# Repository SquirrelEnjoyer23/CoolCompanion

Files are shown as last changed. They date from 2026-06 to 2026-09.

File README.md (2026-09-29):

# Cool Companion



## Cool yourself down today!

A smart table top fan, with adjustable speed and temperature sensing, all powered by usb c.

Perfect for any summer day, or any day... if you just want to move air around.

# Features

This "Cool" fan helps you always stay cool by having adjustable speed and the ability to turn on and off depending on the rooms temperature allowing you to stay cool without the extra work of turning a fan on and off, and on top of that the fan is from Noctua allowing it to be extremely silent as to not interfere with you.

# How to properly use it

The machine is used by plugging a USB C cable into the back, the device requires 5v at 1 Amp, and once its plugged it in does its startup and then you are good to go, turning the knob changes the speed and pressing the knob changes the modes allowing you to use the temperature mode and to turn that back off just turn the temperature requirement back down to zero. with device information available on the screen as well such as current room temp, target temprature and fan speed

# AI Disclosure
This project contains some AI generated code, AI was used for bug finding and putting in features I couldn't find documentation on, as well as adding some polish to the code to have it function a bit smoother for the user.

# What happened?
This project took a absolutely WILD amount of time over the summer due to technical difficulties it only officially recorded about ~43 hours but it took me way more than that in debugging, as well as the sheer number of boards I had to try before finally getting a working one.





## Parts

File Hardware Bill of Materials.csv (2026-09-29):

Item Name | Qty | Price (total) (USD) | Item link | Notes
Noctua Fan | 1 | $34.95 | https://www.amazon.com/Noctua-NF-A12x25-5V-PWM-Premium/dp/B07DXQTCK6/ | The fan that actually moves the air
Usb C connector | 1 | $0.00 | Already had | Usb C connector to recieve power
Rotary Encoder | 1 | $0.00 | Already had | Recieves input from user
Screen | 1 | $19.19 | https://www.amazon.com/waveshare-Resolution-Raspberry-forArduino-Communication/dp/B0CM3RHMGP/ | Shows the current settings
Perf board | 1 | $9.99 | https://www.amazon.com/ELEGOO-Prototype-Soldering-Compatible-Arduino/dp/B072Z7Y19F | Main circuit board
Esp32 | 1 | $0.00 | Already had | Does all the processing
Wires | 1 | $7.98 | https://www.amazon.com/Silicone-Electrical-Colors-Stranded-Flexible/dp/B08F79YG8Q/ | Connects up everything electrically
SHT31-D | 1 | $8.49 | https://www.amazon.com/HiLetgo-Temperature-Humidity-Interface-GY-SHT31-D/dp/B07ZSZW92J/ | Detects current temprature
Screw set | 1 | $12.99 | https://www.amazon.com/Fgruh-1080PCS-Assortment-Washers-Assorted/dp/B0GHVDC8GD/ | M3 screws
Longer screw set | 1 | $9.99 | https://www.amazon.com/Bemaka-420PCS-Button-Washers-Assortment/dp/B0CSYHF18Z/ | M3 screws since i needed longer ones
Straws | 1 | $0.00 | Already had | Hiding wires
Hot glue | 1 | $0.00 | Already had | Putting things together
Shrink wrap | 1 | $1.00 | Already had | Protecting wire connections
Washers | 1 | $5.99 | https://www.amazon.com/Washers-Assortment-Vibration-Absorbing-Plumbing/dp/B0DLL2DZK3/ | Holding the fan in place
Total Price (USD): | $110.57

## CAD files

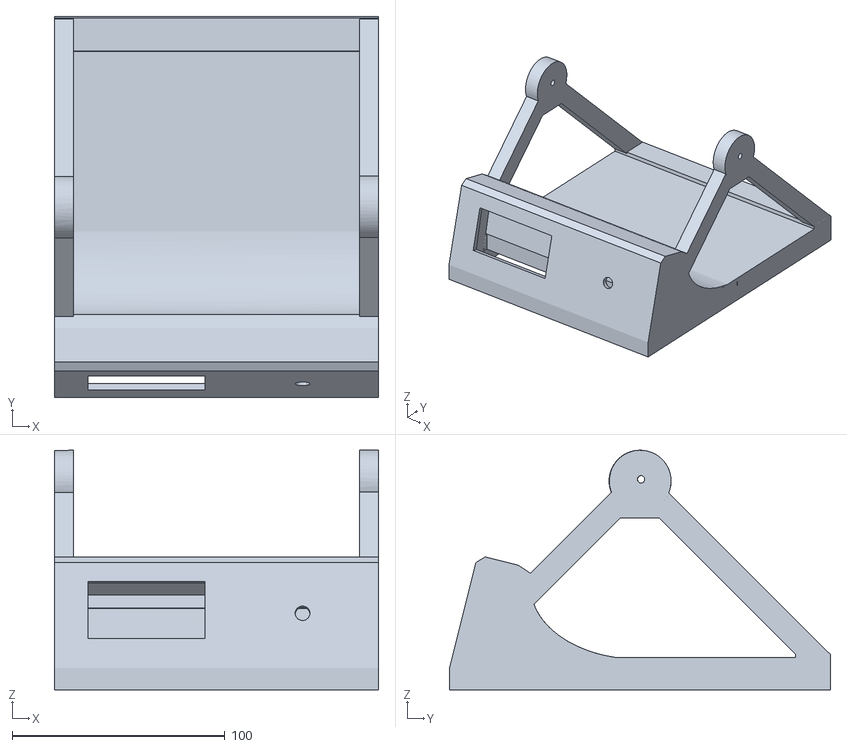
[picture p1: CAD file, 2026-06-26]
3D- Models/Main_Enclosure.stl
152.4 x 178.9 x 112.5

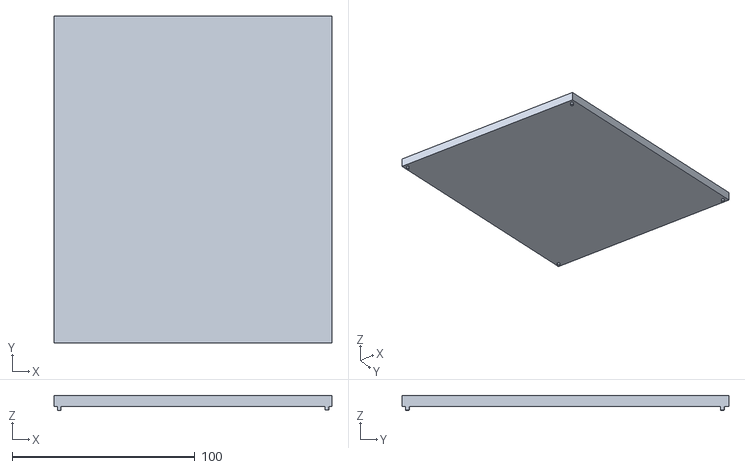
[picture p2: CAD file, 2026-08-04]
3D- Models/Model_Final_Enclosure_Lid.stl
152.2 x 178.9 x 8.03

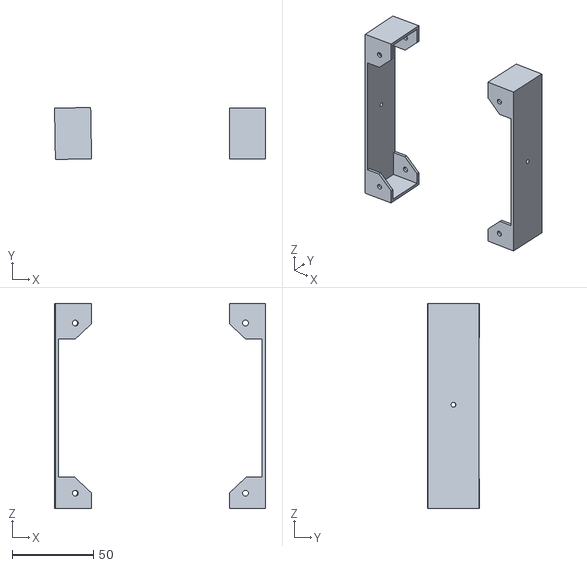
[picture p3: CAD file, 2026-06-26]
3D- Models/Fan Holder.stl
129.7 x 32.0 x 126.1

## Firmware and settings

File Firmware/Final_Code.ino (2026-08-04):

#include <U8g2lib.h>
#include <SPI.h>
#include <Wire.h>
#include "Adafruit_SHT31.h"
Adafruit_SHT31 sht31 = Adafruit_SHT31();
// FAN 
#define FAN_READER_PIN 27
#define FAN_SPEED_PIN 26

// ENCODER
#define ENCODER_CLK 32
#define ENCODER_DT 33
#define ENCODER_SW 25

// OLED
U8G2_SSD1309_128X64_NONAME2_F_4W_HW_SPI u8g2(
  U8G2_R0,
  5,   // CS
  4,   // DC
  U8X8_PIN_NONE
);

// VARIABLES 
bool Current;
bool TurnRight;
bool TurnLeft;
bool IsModeTwo = false;
int LastTurn;
int CurrentTurn;
int TurnNumber = 0;
int HistoricalSpeed;
int lastCLK = HIGH;

float temperature = 0.0;

String TempGather;

String temp2;

String IsModeTwoText;

String PWMString;

String TargetTempString;
int TargetTemp = 0.0;
// FAN SPEED
volatile uint32_t pulseCount = 0;
volatile uint32_t lastPulseMicros = 0;

float rpm = 0;
unsigned long lastTime = 0;

// TACH ISR
void IRAM_ATTR countPulse() {
  uint32_t now = micros();

  // Ignore electrical noise
  if (now - lastPulseMicros > 200) {
    pulseCount++;
    lastPulseMicros = now;
  }
}

// FAN PWM
void SetFanPWM(int percent)
{
  percent = constrain(percent, 0, 100);

  TurnNumber = percent;

  int duty = map(percent, 0, 100, 0, 255);

  // ESP32 Arduino Core 3.x API
  ledcWrite(FAN_SPEED_PIN, duty);
}

int GetFanPWM()
{
  return TurnNumber;
}

// ENCODER
void TurnPercentage(String Direction)
{
  if (Direction == "Right")
  {
    if (IsModeTwo == true)
    {
      TargetTemp = TargetTemp +2;
    }
    if (TurnNumber < 100)
    {
      if (IsModeTwo == true)
      {
        Serial.println("Turning is now turned off");
      } else
      {
        TurnNumber += 5;
      }
     // Serial.println("R");
    }
  }

  if (Direction == "Left")
  {
      if (IsModeTwo == true)
    {
      if (TargetTemp > 0)
      {
        TargetTemp = TargetTemp -2;
      }
    }
    if (TurnNumber > 0)
    {
      if (IsModeTwo == true)
      {
        Serial.println("Turning is now turned off");
      } else
      {
        TurnNumber -= 5;
      }
    //  Serial.println("L");
    }
  }

  SetFanPWM(TurnNumber);
}

void setup()
{
  Serial.begin(115200);
  IsModeTwoText = "false";
  pinMode(ENCODER_SW, INPUT_PULLUP);
  pinMode(ENCODER_CLK, INPUT_PULLUP);
  pinMode(ENCODER_DT, INPUT_PULLUP);

  pinMode(FAN_READER_PIN, INPUT_PULLUP);

  SPI.begin(18, -1, 23, 5);
  u8g2.begin();

  // Fan Tachometer
  attachInterrupt(
    digitalPinToInterrupt(FAN_READER_PIN),
    countPulse,
    FALLING);

  // PWM Output
  ledcAttach(FAN_SPEED_PIN, 25000, 8);
  SetFanPWM(TurnNumber);

  lastCLK = digitalRead(ENCODER_CLK);
  lastTime = millis();

 // Serial.println("Fan Controller Started");

  Wire.begin(21, 22);

if (!sht31.begin(0x44))
{
    Serial.println("Couldn't find SHT31!");
}
else
{
    Serial.println("SHT31 Found");
}
}

void loop()
{
  Current = digitalRead(ENCODER_SW);

  // Encoder 
  int clkState = digitalRead(ENCODER_CLK);

  if (clkState != lastCLK)
  {
    if (digitalRead(ENCODER_DT) != clkState)
    {
      TurnPercentage("Right");
    }
    else
    {
      TurnPercentage("Left");
    }

    lastCLK = clkState;
  }

  // RPM
  unsigned long now = millis();

  if (now - lastTime >= 1000)
  {
    noInterrupts();
    uint32_t count = pulseCount;
    pulseCount = 0;
    interrupts();

    rpm = (count / 2.0f) * 60.0f;

    lastTime = now;
  }

float temp = sht31.readTemperature();

  if (!isnan(temp))
  {
      temperature = temp;
      temp2 = String(int(round(temperature)));
  }

  // OLED
  u8g2.clearBuffer();

  u8g2.setFont(u8g2_font_5x8_tr);
  u8g2.drawStr(0, 13, "Cool Companion");
  u8g2.drawCircle(110, 30, 40);
  u8g2.drawCircle(109,30, 40);
  //u8g2.drawStr(0, 28, ("Mode: " + IsModeTwoText).c_str());
  if (Current == 1)
  {
    CurrentTurn = 1;
  }
  else
  {
    CurrentTurn = 0;

    if (!CurrentTurn == LastTurn)
    {
      Serial.println("NEW");
      if (IsModeTwo == false)
      {
        IsModeTwo = true;
        IsModeTwoText = "true";
      } else
      {
        IsModeTwo = false;
        IsModeTwoText = "false";
      }
    }
  }

  LastTurn = CurrentTurn;
  CurrentTurn = 2;

  if (IsModeTwo == false)
  {
  u8g2.setFont(u8g2_font_ncenB12_tr);
  char pwmText[20];
  PWMString = String(GetFanPWM());
  if (TargetTemp > 0)
  {
    TargetTempString = "Target: "+ String(TargetTemp) + "C";
  } else
  {
    TargetTempString = "Off";
  }
  sprintf(pwmText, PWMString.c_str());
  u8g2.drawStr(94, 32, pwmText);
  u8g2.setFont(u8g2_font_ncenB08_tr);
  u8g2.drawStr(0, 45, TargetTempString.c_str());
  char rpmText[20];
  sprintf(rpmText, "RPM: %.0f", rpm);
  u8g2.drawStr(0, 58, rpmText);

  String TempGather = temp2 + "°C";
  u8g2.drawStr(0, 29, TempGather.c_str());
  } else
  {
  u8g2.setFont(u8g2_font_ncenB12_tr);
  TargetTempString = String(TargetTemp);
  u8g2.drawStr(94, 32, TargetTempString.c_str());
  u8g2.setFont(u8g2_font_ncenB08_tr);
  char pwmText[20];
  PWMString = "Speed: " + String(GetFanPWM());
  sprintf(pwmText, PWMString.c_str());
  u8g2.drawStr(0, 45, pwmText);
  u8g2.setFont(u8g2_font_ncenB08_tr);
  char rpmText[20];
  sprintf(rpmText, "RPM: %.0f", rpm);
  u8g2.drawStr(0, 58, rpmText);

  String TempGather = temp2 + "°C";
  u8g2.drawStr(0, 29, TempGather.c_str());
  }



  if (TargetTemp > temperature && !TargetTemp == 0)
  {
    SetFanPWM(0);
  }

  if (TargetTemp == round(temperature) && !TargetTemp == 0)
  {
    Serial.println("At Temp");
    SetFanPWM(0);
  } else
  {
    if (TargetTemp < round(temperature) && !TargetTemp == 0)
    {
      Serial.println("Temp Is Too High!");
      if (IsModeTwo == true)
      {
      SetFanPWM(100);
      }
    }
  }

  u8g2.sendBuffer();
  delay(10);
}

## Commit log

2026-06-26 Added Enclosure File and added folder
    Added Final Main Enclosure file and main folder
    [Main_Enclosure.stl]
2026-06-26 Added fan file
    Added Fan holder file
    [Fan Holder.stl]
2026-08-04 Added enclosure lid
    [Model_Final_Enclosure_Lid.stl]
2026-09-29 Added Bill Of Materials
    Added Bill Of Materials
    [Hardware Bill of Materials.csv]
